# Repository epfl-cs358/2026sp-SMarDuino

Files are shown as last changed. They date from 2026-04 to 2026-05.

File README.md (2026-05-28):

# SMarDuino : Pick and Place Machine
Assembling electronic boards manually is a slow and error-prone task. Professional **Pick and Place** machines are often expensive or limited in the thickness of components they can handle.

**SMarDuino** transforms a standard **Prusa i3 MK3S+ 3D printer** into a high-precision automated assembly station. By repurposing the printer's rigid frame and precise motion system, we create a machine capable of:
*   Picking different SMD components.
*   Correcting orientation via a **Bottom Camera (OpenCV)**.
*   Placing them accurately on a PCB using a vacuum-controlled nozzle.

## Table of contents
- [The final product](#the-final-product)
- [Bill of materials](#bill-of-materials)
- [Before you start](#before-you-start)
- [Build your machine](#build-your-machine)
    - [1. Nozzle holder](#1-nozzle-holder)
        - [1.1 X-carriage](#11-x-carriage)
        - [1.2 Nozzle tips](#12-nozzle-tips)
        - [1.3 Nozzle](#13-nozzle)
    - [2. Plate](#2-plate)
        - [2.1 The base plate](#21-the-base-plate)
        - [2.2 Feeders: tape](#22-feeders-tape)
        - [2.3 Feeders: individual pieces](#23-feeders-individual-pieces)
        - [2.4 Camera holder](#24-camera-holder)
        - [2.5 PCB holder](#25-pcb-holder)
        - [2.6 Tip holder](#26-tip-holder)
    - [3. On the printer body](#3-on-the-printer-body)
        - [3.1 Pump holder](#31-pump-holder)
        - [3.2 Limit switches](#32-limit-switches)
    - [4. Electronics box](#4-electronics-box)
- [Wire your machine](#wire-your-machine)
    - [1. Electronics and Power](#electronics-and-Power)
    - [2. Camera and computer vision](#camera-and-computer-vision)
---

### The final product
[![Demo GIF]
*Watch our full demo video here: [Project Video Link]*](https://github.com/user-attachments/assets/6840ac97-82fd-42fa-adcd-1b4209363f77)
## Demo video
[See the full demo for big and little components](/github.com/epfl-cs358/2026sp-SMarDuino/issues/44#issuecomment-4560899484)

---

## Bill of materials
### ***Electronics***
*   **Arduino Mega 2560** Board (x1)
*   **Arduino Uno** (x1)
*   **CNC** Shield (x1)
*   Stepper motor **17HS4401** (x5)
*   **A4988** driver (x5)
*   **Air pump RF370** (x1)
*   Air pump tubes (interior diameter 2.5mm and 4mm) (x1)
*   **USB bottom camera** (x1)
*   **USB isolator** (x1)
*   Power supply **12V 10A** (x1)
*   DC Jack (x1)
*   One buck convertor (x1)
*   **8-LED WS2812B NeoPixel** ring light (x1)
*   Jumper wires 

### ***Mechanical parts***
*   **Prusa i3 MK3S+** 3D printer 
*   **MDF board**
*   M2.5 and M3 Screws and nuts
*   2m **Purecrea GT2 belt** (6mm) (x1)
*   Bearing (x1)
*   Bearing (x1)
*   Spring (x1)
*   Insert (x1)
*   Steel rod (x2)

### ***Have access to*** 
*   3D printer with **PETG filament** 
*   Laser cutting machine

---

## Before you start
Before assembling the new parts, you first need to remove some of the original ones from your 3D printer. Grab a screwdriver and remove:
* The heated bed
* The extruder
* If needed, the belts — replace them with new ones

## Build your machine

### 1. Nozzle holder
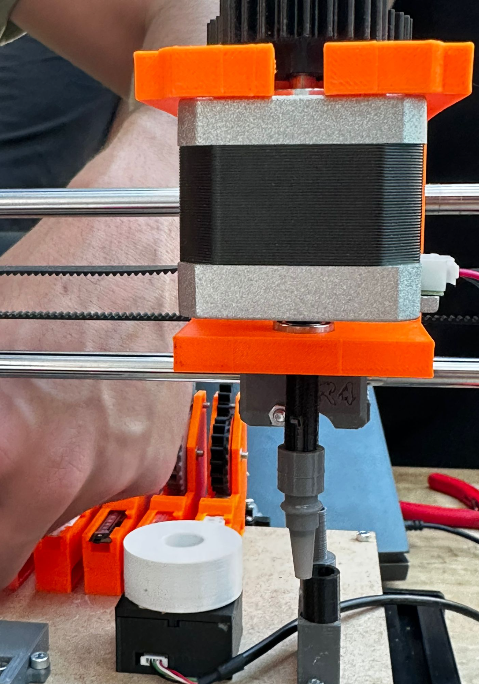
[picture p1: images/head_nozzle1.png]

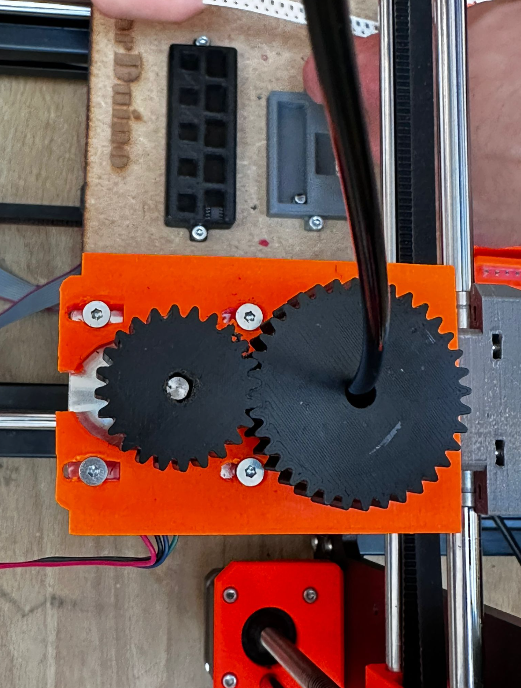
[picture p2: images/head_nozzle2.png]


#### ***1.1 X-carriage***

This assembly replaces the extruder and integrates both the nozzle holder and the feeder-advance trigger. To build it, print the following parts:
* X-carriage
* Nozzle head

Once printed, route the short timing belt through the two X-carriage halves and fasten them together along with the nozzle head. You then need to install:
* The two bearings in their designated seats
* The stepper motor used for nozzle rotation

#### ***1.2 Nozzle tips***
There are currently two tip sizes:
* A small one for components such as resistors, LEDs, etc.
* A larger one for components such as ICs, timers, etc.

PETG is not suitable here — it lacks the dimensional accuracy needed for a 1 mm bore. We therefore printed the tips in resin.

#### ***1.3 Nozzle***
The nozzle is a tube that passes through the two bearings in the nozzle head. Its rotation is driven by the stepper motor through a gear pair. Print the following:
* The nozzle
* The gear

Mount the gear on the stepper-motor shaft, then slide the nozzle through the bearings so the two gears mesh.

### 2. Plate
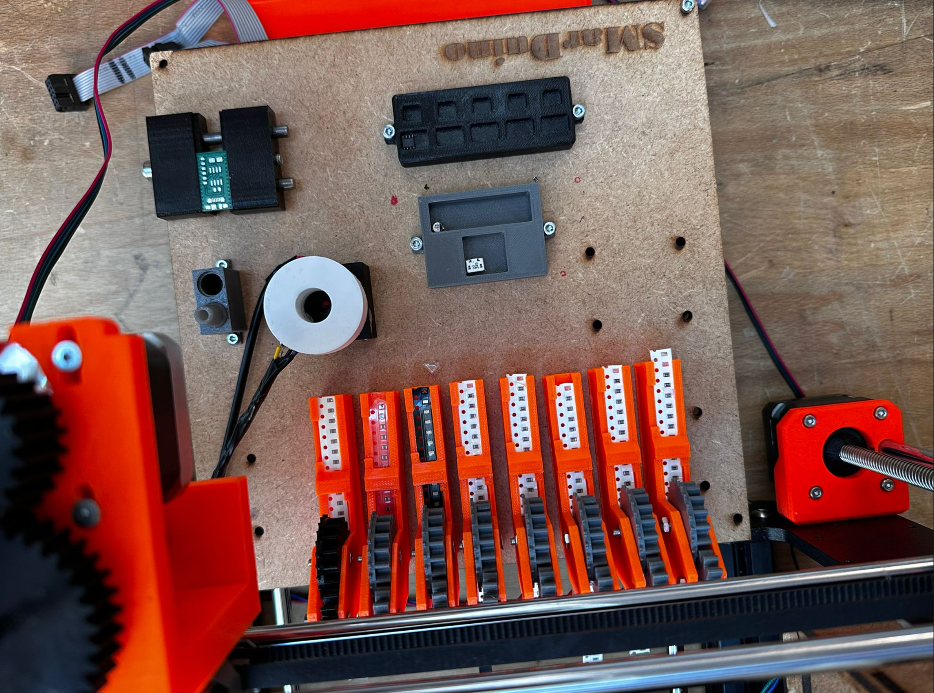
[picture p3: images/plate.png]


#### ***2.1 The base plate***
This replaces the heated bed. It is laser-cut from 4 mm MDF. To stabilize it, first print the spacers that go underneath, then screw the whole assembly down.

#### ***2.2 Feeders: tape***
After evaluating several designs, we settled on a passive mechanical feeder actuated by the nozzle itself. This is a stable and reliable system that also reduces the electrical load and the number of cables routed across the plate.

To build one, print these three pieces:
* Bottom sprocket
* Top gear
* Feeder body

Fasten the bottom sprocket and top gear to the feeder body with screws and nuts, then screw the feeder onto the base plate.

**How it works.** The head moves to the feeder and the vacuum nozzle descends into one of the holes on the tape's carrier strip. A linear move along the tape's axis then pulls the strip forward by one pitch, advancing the next component into the pickup position.

#### ***2.3 Feeders: individual pieces***
For our demo, we hard-designed dedicated holders that fit specific components by geometry. We recommend you either do the same for the components in your own build or rely on additional tape feeders instead.

#### ***2.4 Camera holder***
A small 3D-printed enclosure that holds the bottom-vision camera together with a diffuser for the LED ring light. Print:
* Light diffuser
* Camera holder

Glue the diffuser to the camera box.

#### ***2.5 PCB holder***
Start by printing the two parts contained in the file `PCBHolder`.

The holder uses a spring-loaded clamping design. The assembly consists of two rods, a screw, a spring, and a threaded insert pressed into the moving jaw, which together allow controlled translation to clamp PCBs of different widths. (Refer to the image for details.)

#### ***2.6 Tip holder***

For now this part is only used to store the tips, but it is intended to become the docking station for an automatic tip-change routine.

### 3. On the printer body
#### ***3.1 Pump holder***
A simple bracket mounted on top of the printer frame. Print it and slide the vacuum pump into it.

#### ***3.2 Limit switches***
Limit switches serve three purposes:
* **Homing** — establishing the machine's zero reference at startup
* **Crash protection** — stopping a motor before the head reaches a mechanical end-stop
* **Workspace bounds** — defining the usable travel of each axis in software

We installed one switch per axis (X, Y, Z), three in total. Print the three switch brackets and make sure they are rigidly fixed — a large share of calibration accuracy issues trace back to a loose limit-switch mount.

### 4. Electronics box
To keep the wiring tidy and protected, we designed a laser-cut MDF enclosure. The bottom is left open for easy power-supply routing and Arduino access, and a sliding door provides quick access for last-minute adjustments. 

Once all the parts are cut, assemble them with wood glue. When the box has set, fasten it to the same side of the printer as the X-axis motor, then mount the control circuit on the right-hand inner wall and close the door.

---
## Wire your machine
### 1. Electronics and Power
To avoid electrical noise, we implemented a **Dual Power Supply** system:
1.  **PSU A (12V/10A)**: Dedicated to the 5 high-current stepper motors.
2.  **BUCK Convertor** : from 12V to 5V for the pump

The final electronic architecture of the project contains:

- Arduino Mega connected to the CNC Shield
- Five stepper motor drivers installed and configured
- X, Y, Z and rotation motors connected
- Limit switches added for homing
- Vacuum pump controlled using a transistor switching circuit
- The transistor allows the Arduino to safely activate and deactivate the pump
- Buck converter used to provide a stable power supply for the pump
- Camera system connected for component alignment
- Common ground shared between all electronic modules

This setup allows the machine to perform the full pick-and-place workflow:
homing, component pickup, camera alignment, and PCB placement.
**Circuit Schematic:**
![Electronics Diagram]()
(Capture d'écran 2026-05-21 030021

### 2. Camera and computer vision
The bottom-vision camera looks **upward** at the nozzle so that, with a component held against the tip, the system can verify its orientation before placement and apply a rotation correction if needed.

The camera is paired with an **8-LED WS2812B NeoPixel ring** (32 mm outer / 18 mm inner diameter) that surrounds the lens. Ring illumination is essential here: it provides even, shadow-free lighting on the underside of the component, which is what the vision pipeline relies on to extract a clean silhouette and a stable orientation reading. The ring is driven from a single Arduino digital pin via the Adafruit NeoPixel library.

#### ***Wiring Diagram***
Based on the implementation, the connections are as follows:

| Ring Light Wire | Arduino Pin | Function |
| :--- | :--- | :--- |
| **Red** | **5V** | Power Supply (Stable 5V for LED consistency) |
| **Black** | **GND** | Ground |
| **Purple/blue** | **D10** | Signal / Control Pin 10 |
| **Yellow** | **D11** | Signal / Control Pin 11 |

---

## Running the software

### Software Layers
SMarDuino runs on a three-tier software architecture:

*   **Layer 1 (Firmware)**: Custom G-Code interpreter on Arduino Mega to handle XYZ movements and vacuum solenoid. [README of the WebApp](./3d-placer-monitor/README.md).
*   **Layer 2 (Vision)**: Python script using **OpenCV** to detect component contours, extract rotation angles, and send correction commands. [README of the computer vision](./computer_vision/README.md).
*   **Layer 3 (UI)**: A web dashboard to upload PCB design files (CSV) and monitor the placement progress in real-time.
*   
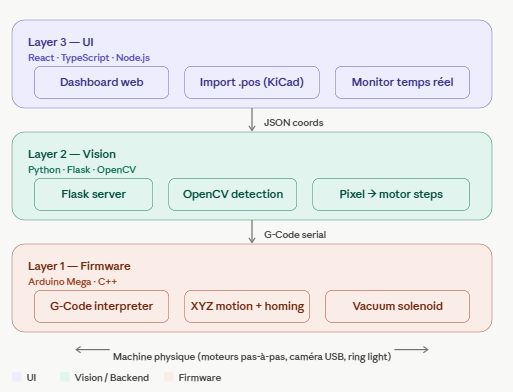
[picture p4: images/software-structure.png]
Architecture
  

### Prerequisites
- **Node.js** ≥ 18 and **npm**
- **Python** ≥ 3.10 with `pip`
- **Arduino IDE** (or `arduino-cli`)
- A USB-A cable to the Arduino Mega

### 1. Flash the firmware
1. Open `3d-placer-monitor/placer_4axis/placer_4axis.ino` in the Arduino IDE.
2. Install the **AccelStepper** library via *Sketch → Include Library → Manage Libraries → search "AccelStepper" → Install*.
3. Select board: **Arduino Mega 2560**, select the right serial port, click **Upload**.
4. Open the Serial Monitor at **9600 baud** to confirm the `READY` banner appears, then close it (only one process can own the serial port at a time).

### 2. Start the web dashboard
```bash
cd 3d-placer-monitor
npm install
npm start
```
Open **http://localhost:3000** for the Monitor view, or **http://localhost:3000/placement.html** for the Placement view. Pick the Arduino's COM port from the dropdown and click **Connect**.

### 3. Run the bottom-vision module
```bash
cd computer_vision
python vision_bridge.py --camera 1 --port 5001 --pcb "C:path\to\your\pos\file.csv"
```
Open it on **http://localhost:3000/vision.html** 

Change the camera index if it is the wrong one

## Acknowledgments

### Contributers
*   [**Alae Messaoudi**](https://github.com/alaemessaoudi)
*   [**Khalil Romdhane**](https://github.com/khalilromdhane)
*   [**Yahya Boussaadia**](https://github.com/yahyaboussaadia)
*   [**Yosr Hallab**](https://github.com/yosrhallab)
*   [**Zeineb Sellami**](https://github.com/zeinebsellami) 

We would like to thank our professor and TAs for the guidance and the patience throughout the whole semester. Special thanks to the friends who showed up, stayed late, and cheered when a single resistance finally landed where it was supposed to.
And a moment of silence, for all the A4988 drivers who gave their lives so this project could move. Gone, but not forgotten. 

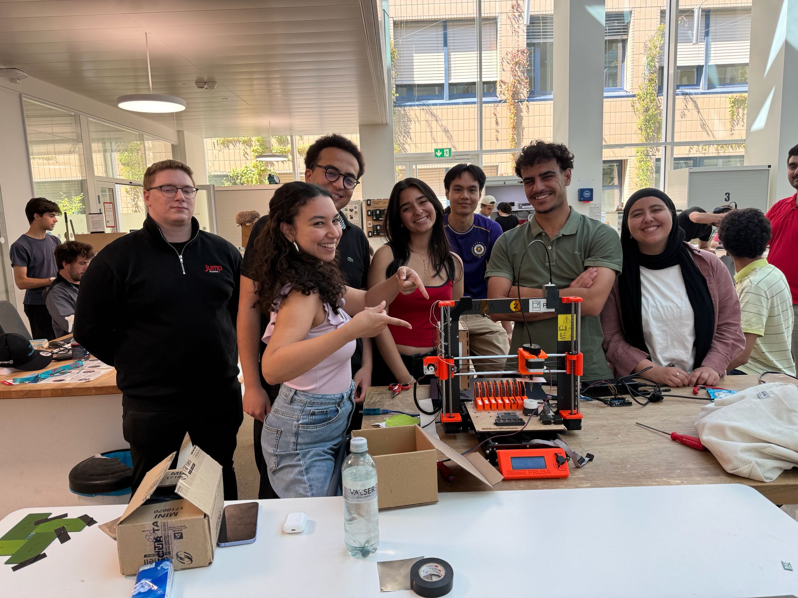
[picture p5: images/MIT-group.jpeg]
team photo


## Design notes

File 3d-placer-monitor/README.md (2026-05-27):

# 3D Placer — Web Control System

Web-based monitor & control for a 4-axis (X, Y, Z, R) pick-and-place machine using a CNC Shield + Arduino Mega.

## ✨ Features

- 📡 **Live monitoring** — X / Y / Z / R positions in real time
- 🗺️ **XY trail map** — visual movement history
- 📷 **USB webcam feed**
- 📂 **KiCad .pos import** — drag & drop component placement files
- ⚙️ **Capture buttons** — jog the head, click ⊕ to grab the current position
- ⚙️ **Persistent config** — feeders, camera, PCB origin saved to disk
- 🎯 **Automated placement** — full pick & place workflow
- ⏯️ **Run controls** — Start / Pause / Skip / Stop
- 🔒 **Limit switch homing** — real homing with NC switches
- ⌨️ **Manual commands** — send any command directly to the Arduino

---

## 🔌 Hardware

**Board:** Arduino Mega 2560 + CNC Shield V3

| Function | Pin | Notes |
|---|---|---|
| X STEP / DIR | 2 / 5 | CNC Shield X slot |
| Y STEP / DIR | 3 / 6 | CNC Shield Y slot |
| Z STEP / DIR | 4 / 7 | CNC Shield Z slot |
| R STEP / DIR | 18 / 17 | Separate driver (rotation) |
| R ENABLE | 19 | Dedicated enable for rotation driver |
| ENABLE (X/Y/Z) | 8 | Shared CNC Shield enable |
| Vacuum pump | A0 | Via relay or MOSFET |
| X limit switch | 14 | NC, wired to GND, INPUT_PULLUP |
| Y limit switch | 15 | NC |
| Z limit switch | 16 | NC |

**Homing directions:** X positive, Y negative, Z negative

---

## 🛠️ Setup

### 1. Install Node.js
https://nodejs.org (v18+)

### 2. Install dependencies
```bash
cd 3d-placer-monitor
npm install
```

### 3. Install AccelStepper library
Arduino IDE → Sketch → Include Library → Manage Libraries → search **"AccelStepper"** → Install

### 4. Upload the Arduino sketch
Open `placer_4axis.ino` → select **Arduino Mega 2560** → Upload.

### 5. Start the web server
```bash
npm start
```

### 6. Open the dashboards
- Monitor:   http://localhost:3000
- Placement: http://localhost:3000/placement.html

---

## 📡 Arduino command protocol

Every command returns `OK` or `ERR: <reason>` when complete.

| Command | Description |
|---|---|
| `MOVE X<n> Y<n> Z<n> R<n>` | Absolute move (any subset of axes) |
| `PICK` | Lower Z to Z_PICK, vacuum ON, raise Z |
| `PLACE` | Lower Z to Z_PLACE, vacuum OFF, raise Z |
| `VAC ON` / `VAC OFF` | Manual vacuum control |
| `HOME` | Home all axes (Z first for safety) |
| `HOME X` / `HOME Y` / `HOME Z` | Home one axis |
| `STATUS` | Report current X Y Z R |
| `STOP` | Immediate stop |
| `SPEED <n>` | Set max speed in steps/sec |

**All coordinates are in STEPS, not mm.** What you send is what the motor does.

---

## 🎯 Placement workflow

1. **Home the machine** — send `HOME` (uses limit switches)
2. **Jog the head** to each fixed position using the JOG panel
3. **Click ⊕ CAPTURE** to grab the current position into the config:
   - PCB origin (bottom-left corner of where the PCB will sit)
   - Camera position
   - Z Travel (safe height to fly between points)
   - Z Pick (touching the feeder)
   - Z Place (touching the PCB)
   - Each feeder XY (one ⊕ per feeder row)
4. **Set Steps per mm** — calibrate so .pos mm coords convert correctly
5. **Click SAVE CONFIG**
6. **Export .pos from KiCad** → File → Fabrication Outputs → Component Placement
7. **Drag the .pos file** onto the upload zone in the placement dashboard
8. **Click ▶ START** — the machine runs through every component

---

## 📏 Calibrating "steps per mm"

The .pos file uses mm. Your machine uses steps. The conversion factor:

1. From the dashboard, send `HOME` then `MOVE X1000`
2. The head moves 1000 steps. **Measure the distance in mm.**
3. Compute: `steps_per_mm = 1000 / mm_moved`
4. Enter this value in the SETUP panel → SAVE CONFIG

Typical values:
- GT2 belt + 20T pulley + 1/16 microstep: ~80
- Leadscrew M5 + 1/16 microstep: ~400

---

## 🔒 Limit switch homing

The sketch implements real homing using your NC limit switches:
- **Each axis drives at a constant speed** toward its switch
- **The motor stops the instant the switch triggers** (NC switch opens when pressed → pin reads HIGH)
- **Current position is set to 0** at the switch
- **During normal moves**, the same switches act as safety: if the motor is moving *toward* its switch and the switch triggers, the motor stops immediately (with debouncing to avoid false triggers)

---

## ⚠️ Safety notes

- **Close Arduino IDE Serial Monitor** before running `npm start` (only one program can use a COM port)
- **Set driver current limits** before powering motors (~0.5-1A to start)
- **Add 100µF capacitor** across VMOT/GND near each driver
- **Test moves at low speed first**
- **Always `HOME`** at startup so position is known

---

## 🐛 Troubleshooting

| Problem | Fix |
|---|---|
| "Cannot open COM port" | Close Arduino IDE Serial Monitor |
| Z homes but doesn't stop at switch | Wrong `Z_LIMIT_IS_POSITIVE` value in the sketch |
| Motor moves wrong direction in homing | Flip sign of `_HOMING_SPEED` constant |
| All axes drift over time | Driver current too low — increase trim pot voltage |
| Component placed wrong spot | Re-capture PCB origin / verify rotation |

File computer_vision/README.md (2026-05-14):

# Vision PnP — Bottom-View Orientation System

SMD pick-and-place orientation checker for a Prusa MK3S+ conversion.
One upward-facing camera is mounted on the bed; components are inspected
after pickup, before placement.

---

## Files

| File | Purpose |
|---|---|
| `orientation_engine.py` | Detection core — `load_pcb`, `VisionPipeline`, `check_orientation` |
| `footprint_envelopes.py` | Geometric envelopes for WRONG_PART detection |
| `placement_sequencer.py` | Production orchestrator — `PlacementSequencer` |
| `run_placement.py` | Automated placement CLI (production use) |
| `pnp_bottom_vision.py` | Manual debug / tuning tool (keep for calibration) |
| `camera_diagnostic.py` | Threshold-tuning utility |
| `test_pnp_vision.py` | Full test suite (no camera or Arduino required) |
| `pcb_centroid.csv` | Example centroid file |

---

## Quick start

```bash
pip install opencv-python pyserial numpy

# Manual debug tool (keyboard navigation)
python pnp_bottom_vision.py

# Automated placement loop
python run_placement.py

# Run all tests (no hardware required)
python test_pnp_vision.py
```

---

## Sequencer flow

```
load_job(pcb_file)
      │
      ▼
┌─────────────────────────────────────────────────────┐
│  for each component in centroid order:              │
│                                                     │
│  1. Wait for trigger (READY <des> or function call) │
│  2. Capture one frame from bottom camera            │
│  3. VisionPipeline.run(frame) → DetectedComponent   │
│  4. is_consistent_with(detected, footprint)         │
│        ↓ fail → WRONG_PART  halt, operator skip     │
│  5. check_orientation(detected, pcb_comp)           │
│        PLACE     → send JSON, wait ACK, advance     │
│        ROTATE_*  → send JSON, wait ACK, retry once  │
│        REJECT    → WRONG_PART halt                  │
└─────────────────────────────────────────────────────┘
```

### Keyboard shortcuts (run_placement.py)

| Key | Action |
|---|---|
| `SPACE` | Process current expected designator |
| `s` | Skip (operator override after WRONG_PART halt) |
| `r` | Reset queue to start |
| `d` | Toggle debug body-mask overlay |
| `q` | Quit |

---

## Serial protocol

### Host → Arduino (one JSON line per component)

```json
{"des":"R1","ok":true,"type":"SMD_PASSIVE","delta":-12.3,"action":"ROTATE_CCW","conf":0.72,"method":"pads","pads":2,"pin1":"unknown"}
```

| Field | Type | Description |
|---|---|---|
| `des` | string | Designator from centroid file |
| `ok` | bool | `true` when within ANGLE_TOLERANCE (5°) |
| `type` | string | Detected component class |
| `delta` | float | Signed rotation needed (CCW-positive, degrees) |
| `action` | string | `PLACE` / `ROTATE_CW` / `ROTATE_CCW` / `REJECT` / `WRONG_PART` |
| `conf` | float | Detection confidence 0–1 |
| `method` | string | Angle method used: `pads` / `pca_pads` / `pca` / `bbox` |
| `pads` | int | Pad count detected |
| `pin1` | string | `"left"` / `"right"` / `"unknown"` — IC pin-1 hint |

### Arduino → Host (ACK)

```
ACK R1 PLACED
ACK U2 ROTATED
ACK R3 ERROR
```

The sequencer blocks up to **5 seconds** for the ACK.  Timeout or `ERROR`
halts the sequence and requires operator intervention.

---

## Rotation convention

KiCad uses **CCW-positive degrees**.  The engine preserves this end-to-end.
The Arduino receives the same sign convention — positive delta means rotate
counter-clockwise.

For components placed on the **bottom layer**, the required rotation is
mirrored: `required_angle = (-pcb_rotation) % 360`.

---

## Footprint envelopes (WRONG_PART detection)

`footprint_envelopes.py` maps footprint strings to geometric envelopes
`(pad_count_range, aspect_ratio_min, body_area_range)`.  Matching is by
case-insensitive substring, so `"R_0805"` matches both `"R_0805"` and
`"Resistor_SMD:R_0805_2012Metric"`.

If no envelope is defined for a footprint the check is skipped (proceed).
To add a new footprint, add an entry to `FOOTPRINT_ENVELOPES` in
`footprint_envelopes.py`.

---

## Pin-1 detection (IC packages)

Bottom-view pin-1 detection for symmetric SOIC packages is **inherently
unreliable** — many ICs look identical from below.  The sequencer surfaces a
`pin1_side` hint (`"left"` / `"right"` / `"unknown"`) based on pad-area
asymmetry, but proceeds regardless of the result.  The feeder orientation is
the real source of truth.  A top camera would make this reliable; we can
revisit when/if one is added.

---

## Running tests

```bash
python test_pnp_vision.py
```

Runs three suites:

1. **Vision tests** — synthetic frames through the full detection pipeline
2. **Loader tests** — CSV and KiCad PCB file parsers
3. **Sequencer tests** — `PlacementSequencer` in offline mode (no hardware)

All tests run without a camera or Arduino.

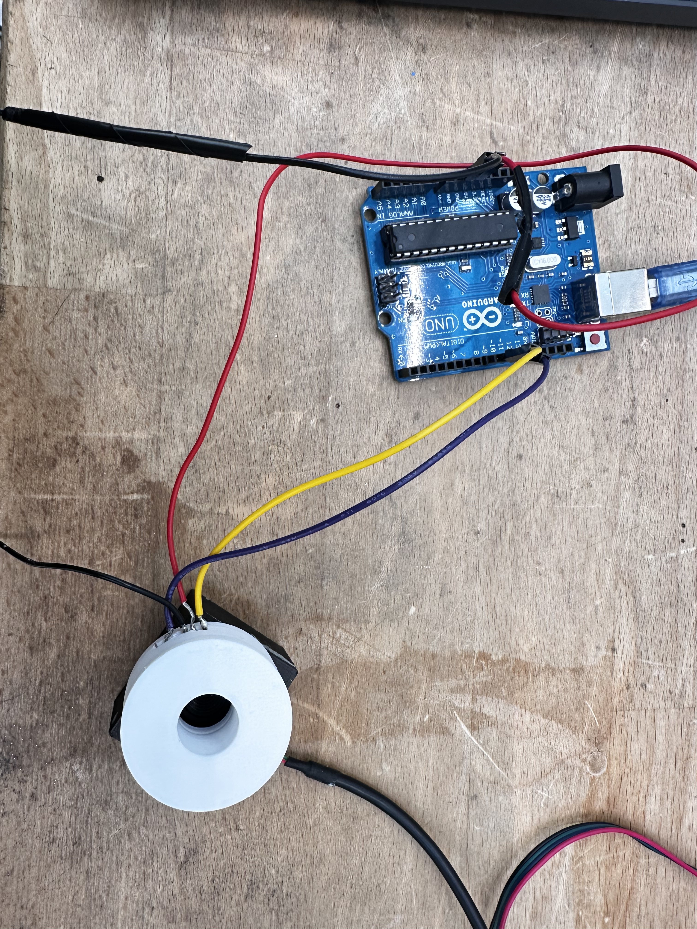
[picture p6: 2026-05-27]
images/computer_vision_electronics3.jpeg

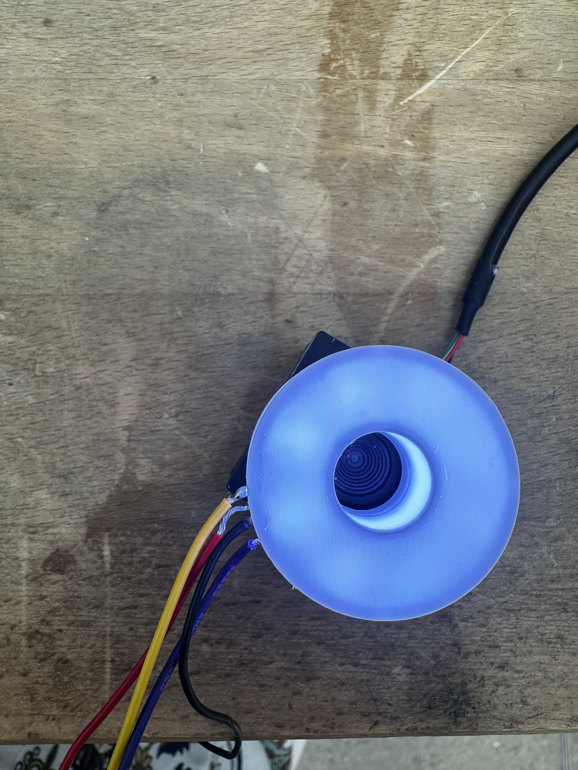
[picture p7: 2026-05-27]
images/computer_vision_electronics1.jpeg

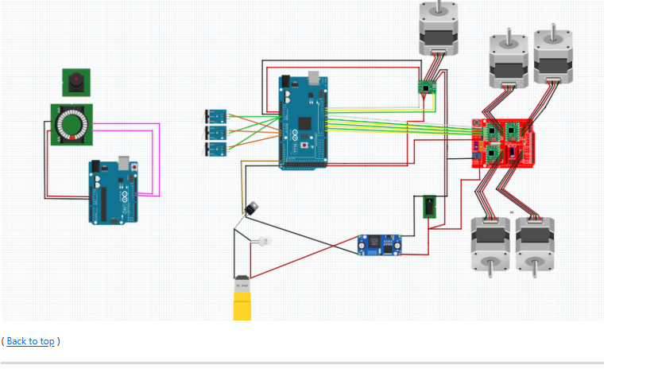
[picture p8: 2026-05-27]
images/electronic circuit.png

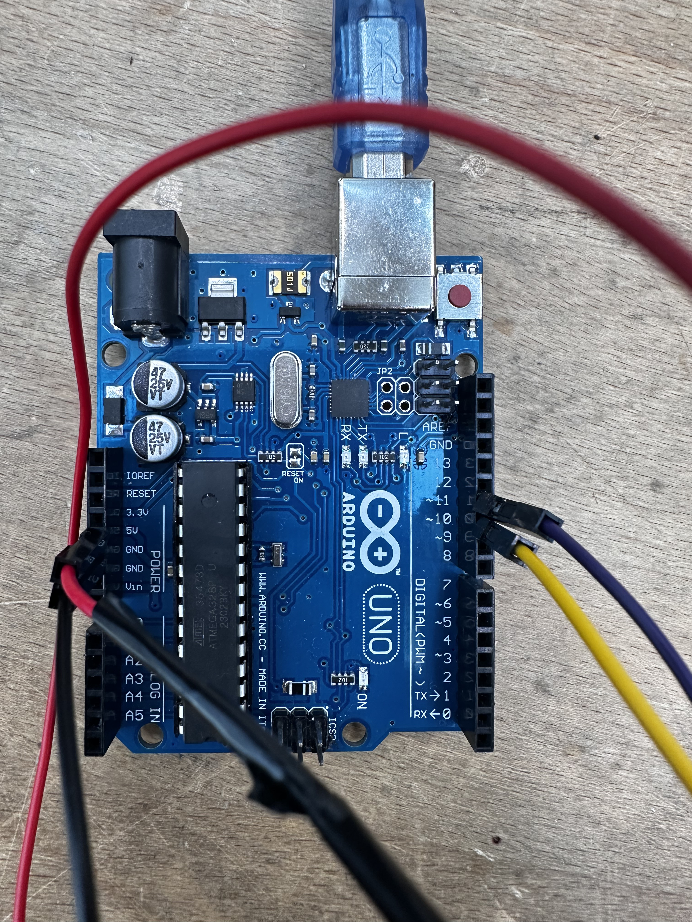
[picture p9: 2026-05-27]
images/computer_vision_electronics2.jpeg

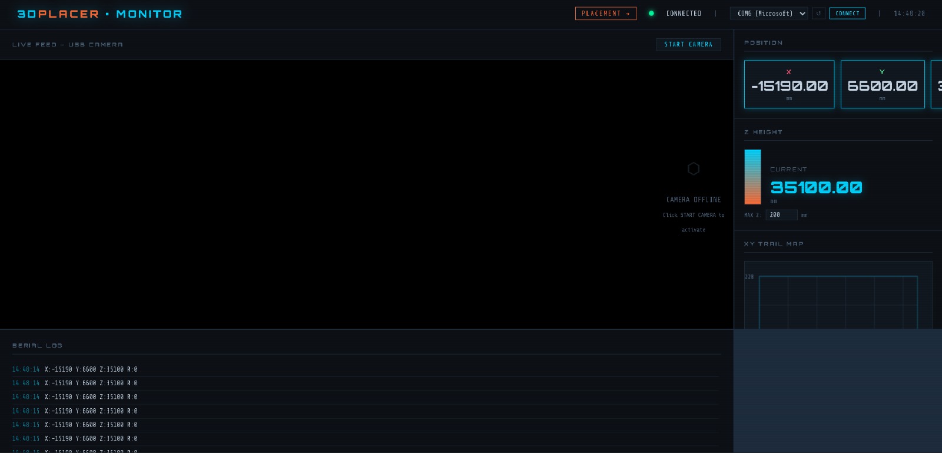
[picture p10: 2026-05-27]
images/Webapp_monitor.jpeg

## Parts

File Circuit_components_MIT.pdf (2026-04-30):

## Bill of Materials

SMD PCB Circuits — Pick & Place Demonstration

All components available in Switzerland

April 29, 2026

Contents

1 Circuit 1 — Flashing LED (NE555 Astable) | 2
2 Circuit 2 — LED Chaser / Knight Rider (NE555 + CD4017) | 2
3 Combined Bill of Materials | 2

Circuit 1 — Flashing LED (NE555 Astable)

Description

A minimal SMD LED flasher based on the NE555 timer IC in astable mode. Flashes a single red LED at a fixed frequency set by resistors and capacitor. Power via USB Micro-B connector. Repository: github.com/ItsKarlito/flashing-led

Component List

- 1x NE555DR — Timer IC, SOIC-8
- 1x LED, Red, SMD 0805
- 1x USB Micro-B Connector, Female, SMD
- 1x Capacitor 1 uF, SMD Electrolytic
- 1x Resistor 100 kOhm, SMD 0805
- 1x Resistor 470 kOhm, SMD 0805
- 1x Resistor 270 kOhm, SMD 0805

Circuit 2 — LED Chaser / Knight Rider (NE555 + CD4017)

Description

A 10-LED running light chaser. The NE555 generates a clock in astable mode, driving the CD4017 decade counter. Each output lights one LED in sequence. Power supply: 9V DC. Reference: PCBWay — NE555 LED Chaser Board (https://www.pcbway.com/project/shareproject/NE555_IC_Timer_LED_Chaser_Board_d9795bc6.html)

Component List

- 1x NE555DR — Timer IC, SOIC-8
- 1x CD4017BM96 — Decade Counter IC, SOIC-16
- 10x LED, Red, SMD 0805
- 1x Resistor 10 kOhm, SMD 0805
- 10x Resistor 220 Ohm, SMD 0805
- 1x Capacitor 10 nF, SMD Ceramic 0805
- 1x Capacitor 10 uF, SMD Ceramic 0805

Combined Bill of Materials

Component / MPN | Qty Package | Supplier | Verified Link

NE555DR
Timer IC | 2 | SOIC-8 | mouser.ch | Search: NE555DR (https://www.mouser.ch/Search/Refine?Keyword=NE555DR)
CD4017BM96
Decade Counter | 1 | SOIC-16 | mouser.ch | Search:
| | | | CD4017BM96 (https://www.mouser.ch/Search/Refine?Keyword=CD4017BM96)
VLMS1300-GS08
LED, Red | 11 | SMD 0805 | mouser.ch | Search: VLMS1300 (https://www.mouser.ch/Search/Refine?Keyword=VLMS1300-GS08)
RND 1550805S8F2200T5E
Resistor 220 Ohm | 10 | SMD 0805,
| | 1% | distrelec.ch | Art. 30056759 (https://www.distrelec.ch/en/thick-film-smd-resistor-0805-220ohm-125mw-rnd-rnd-1550805s8f2200t5e/p/30056759)

RND 1550805S8F1002T5E
Resistor 10 kOhm | 1 | SMD 0805,
| | 1% | distrelec.ch | Art. 30056718 (https://www.distrelec.ch/en/thick-film-smd-resistor-0805-10kohm-125mw-rnd-rnd-1550805s8f1002t5e/p/30056718)

RC0805FR-07100KL
Resistor 100 kOhm | 1 | SMD 0805,
| | 1% | mouser.ch | Search:
| | | | RC0805FR-07100KL (https://www.mouser.ch/Search/Refine?Keyword=RC0805FR-07100KL)
RC0805FR-07270KL
Resistor 270 kOhm | 1 | SMD 0805,
| | 1% | mouser.ch | Search:
| | | | RC0805FR-07270KL (https://www.mouser.ch/Search/Refine?Keyword=RC0805FR-07270KL)
RC0805FR-07470KL
Resistor 470 kOhm | 1 | SMD 0805,
| | 1% | mouser.ch | Search:
| | | | RC0805FR-07470KL (https://www.mouser.ch/Search/Refine?Keyword=RC0805FR-07470KL)
C0805C103K5RACTU
Cap 10 nF | 1 | SMD 0805,
| | X7R, 50V | distrelec.ch | Art. 16572413 (https://www.distrelec.ch/en/ceramic-capacitor-10nf-50vdc-0805-10-kemet-c0805c103k5ractu/p/16572413)

EEE-FK1H010P
Cap 1 uF | 1 | SMD
| | Electrolytic | mouser.ch | Search:
| | | | EEE-FK1H010P (https://www.mouser.ch/Search/Refine?Keyword=EEE-FK1H010P)
CC0805KKX5R8BB106
Cap 10 uF | 1 | SMD 0805,
| | 25V | distrelec.ch | Art. 30288132 (https://www.distrelec.ch/en/ceramic-capacitor-10uf-25v-0805-10-yageo-cc0805kkx5r8bb106/p/30288132)

47346-0001 (Molex)
USB Micro-B | 1 | Female,
| | SMD, 5-pin | mouser.ch | Search: 47346-0001 (https://www.mouser.ch/Search/Refine?Keyword=47346-0001)

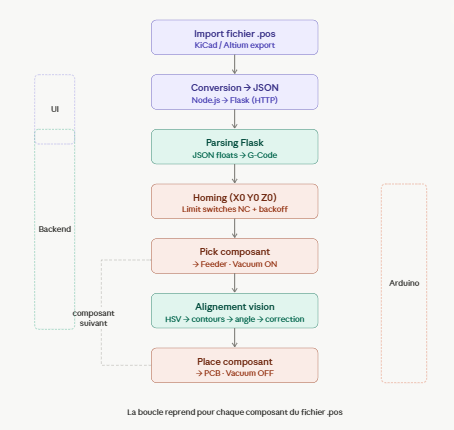
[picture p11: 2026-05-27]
images/placement-component.png

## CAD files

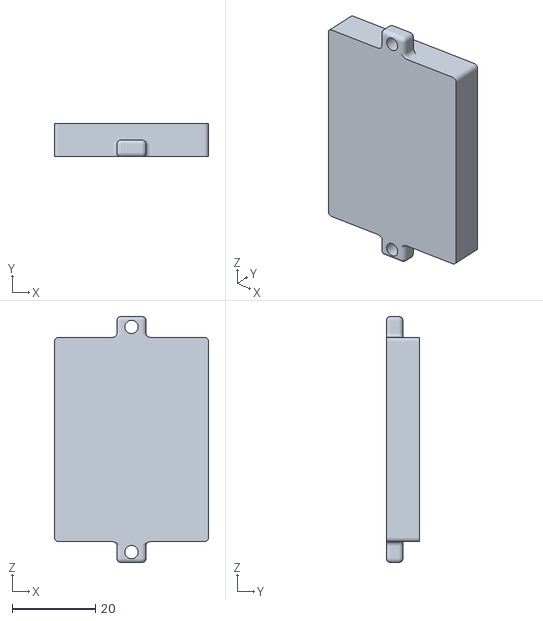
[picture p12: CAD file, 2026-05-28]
3D_designs/bigbigcomponents2.stl
37.0 x 8.00 x 59.1

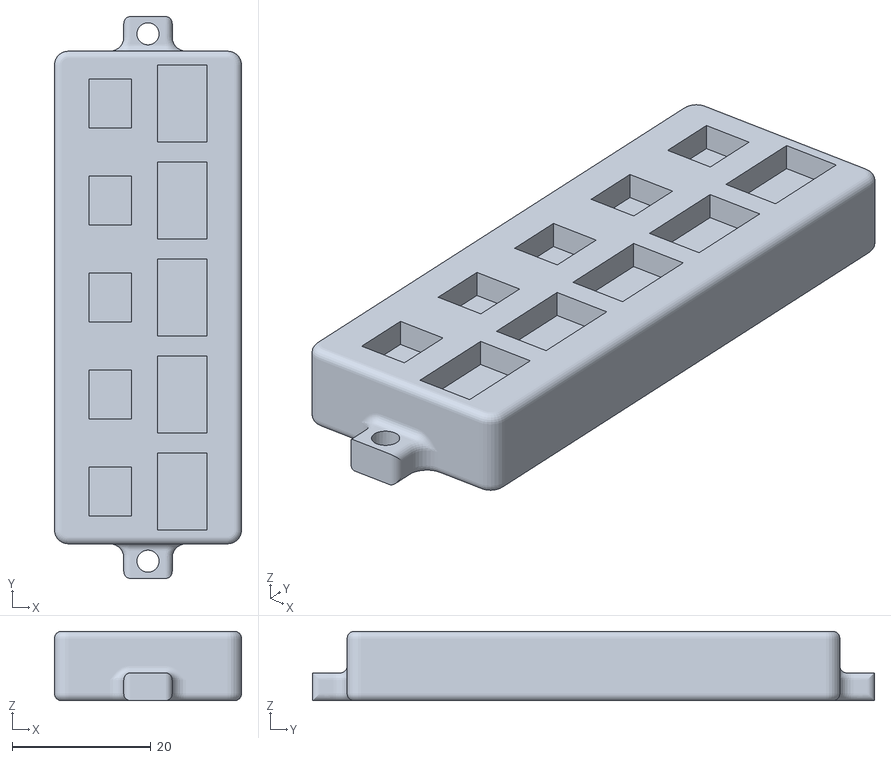
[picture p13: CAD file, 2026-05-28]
3D_designs/feeder2.stl
27.0 x 81.1 x 10.0

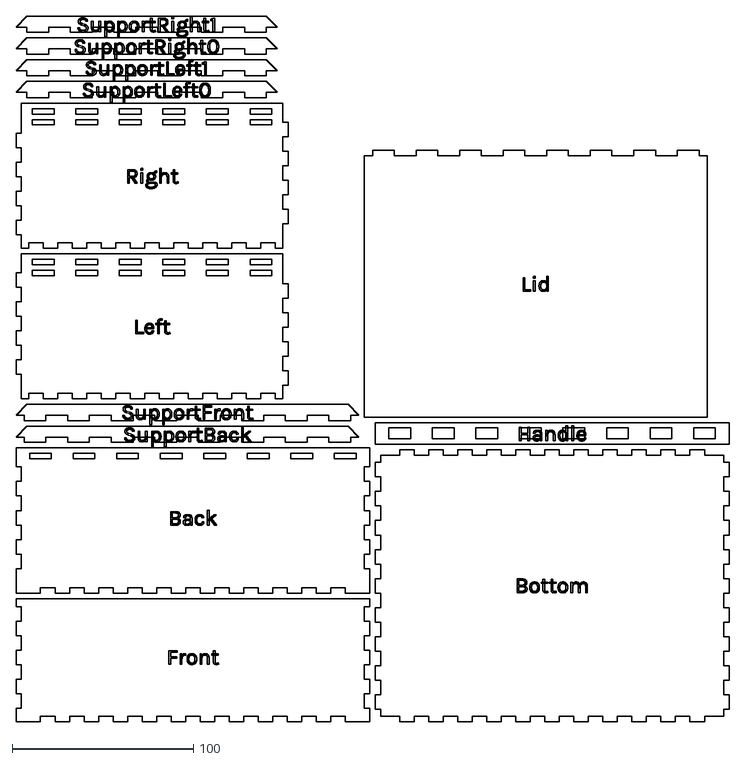
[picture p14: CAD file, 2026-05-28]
3D_designs/box (1).dxf
393.0 x 389.0

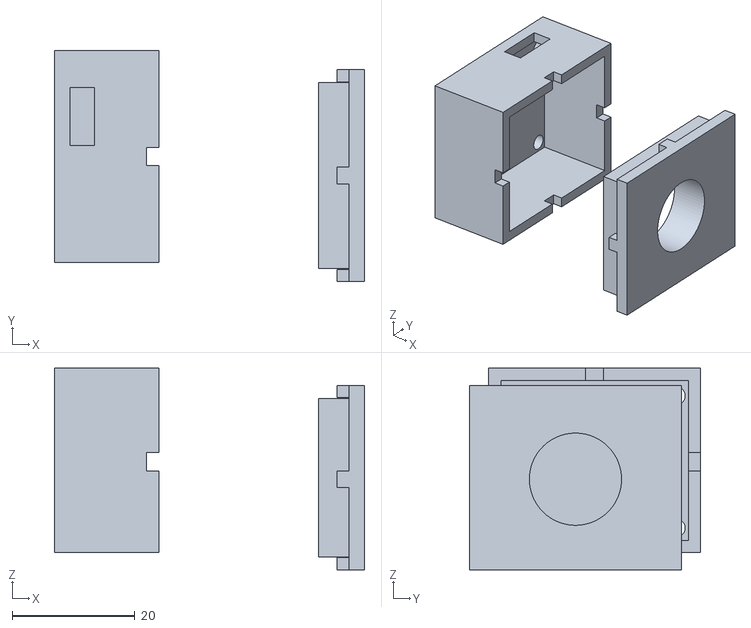
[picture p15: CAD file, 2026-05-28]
3D_designs/holdcamera.stl
50.4 x 37.6 x 32.8

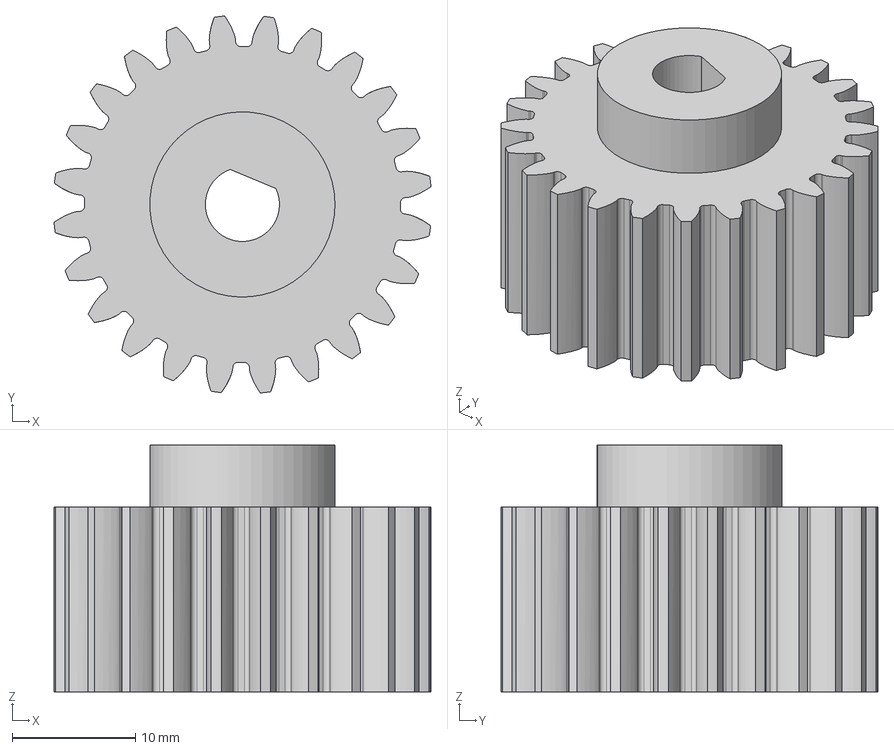
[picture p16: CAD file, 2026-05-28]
3D_designs/NozzleGear.step
30.5 x 30.5 x 20.0 mm

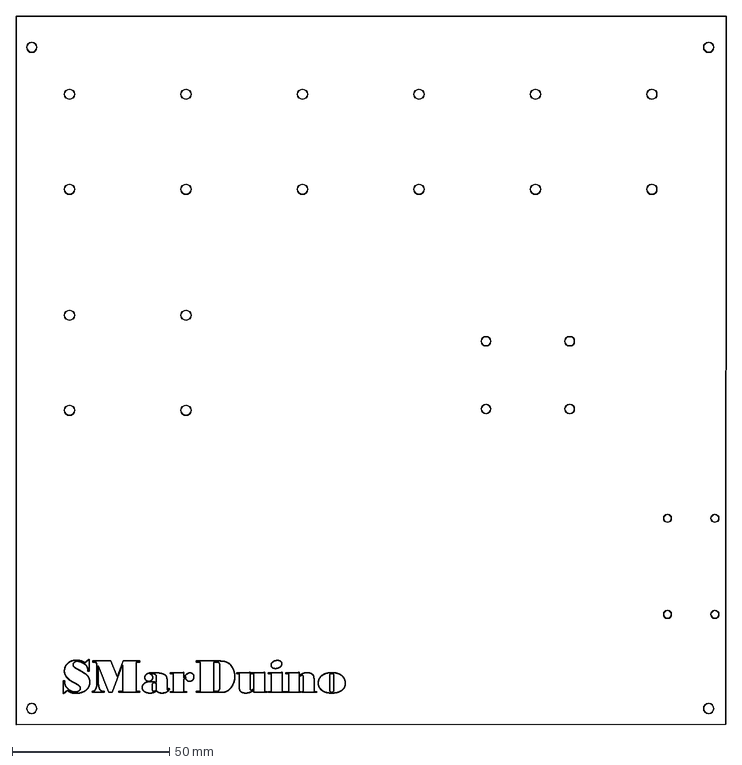
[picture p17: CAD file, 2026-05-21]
3D_designs/Plate.dxf
225.5 x 224.9 mm

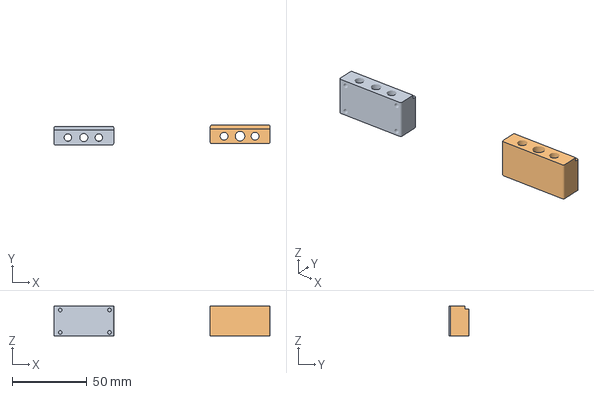
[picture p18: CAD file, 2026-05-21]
3D_designs/PCBHolder.3mf
144.6 x 13.4 x 20.0 mm
MON PCB HOLDER.stl_1
MON PCB HOLDER.stl_2

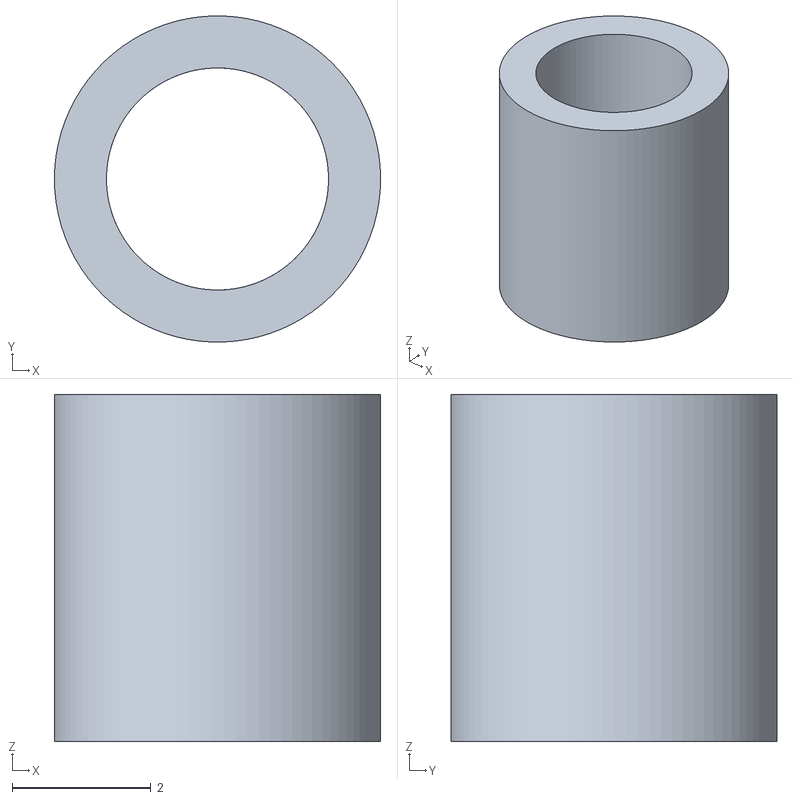
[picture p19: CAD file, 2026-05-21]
3D_designs/PlateSpacer.stl
4.70 x 4.70 x 5.00

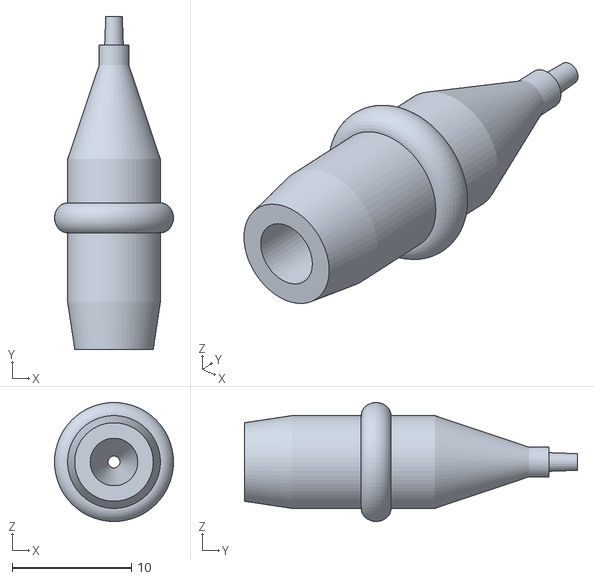
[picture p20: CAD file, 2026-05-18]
3D_designs/TipSmall.stl
10.0 x 28.0 x 10.0

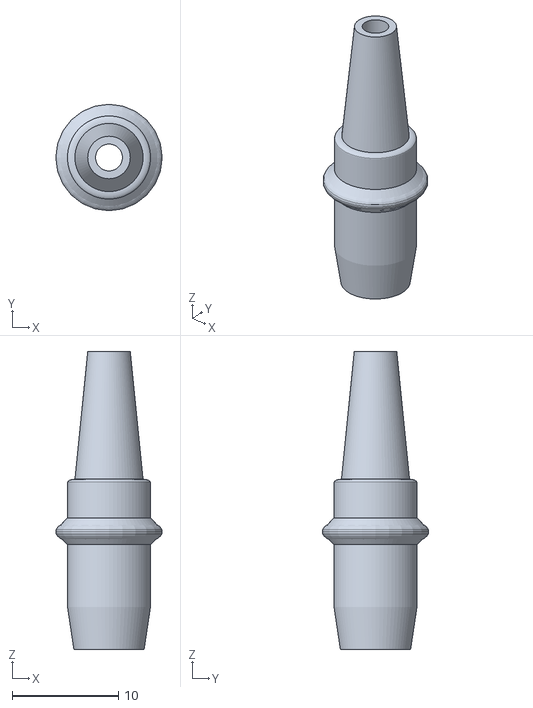
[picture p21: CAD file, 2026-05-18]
3D_designs/TipBig.stl
10.0 x 10.0 x 28.0

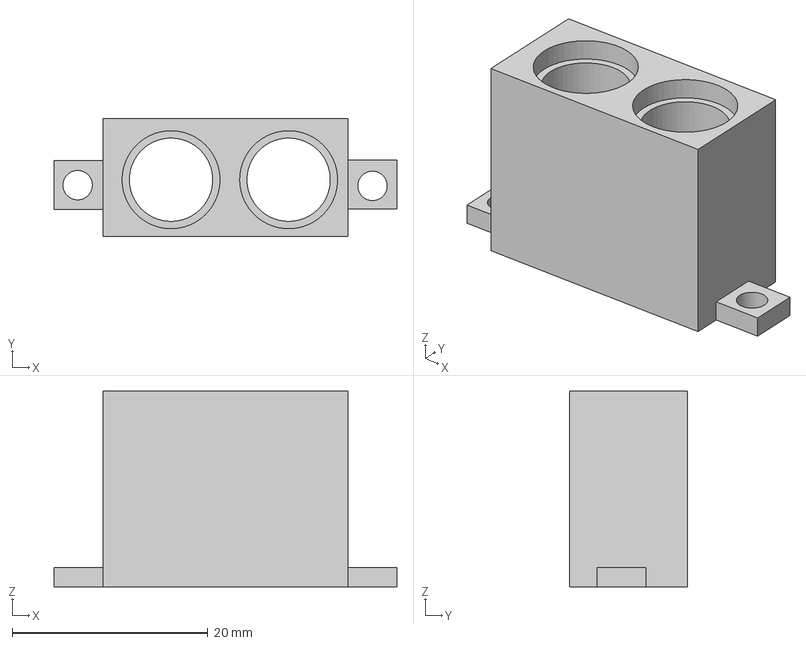
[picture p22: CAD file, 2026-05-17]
3D_designs/TipHolder.step
35.0 x 12.0 x 20.0 mm

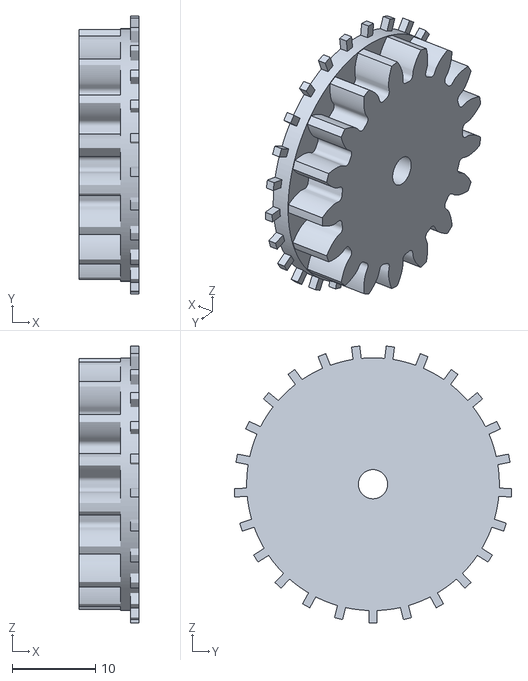
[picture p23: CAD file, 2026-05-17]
3D_designs/BottomSprocket.stl
7.20 x 33.3 x 33.2

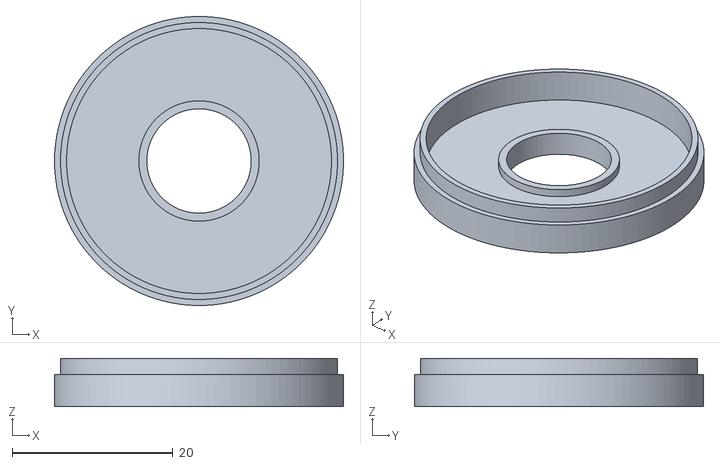
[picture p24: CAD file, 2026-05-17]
3D_designs/BottomLightHolder.stl
36.0 x 36.0 x 6.00

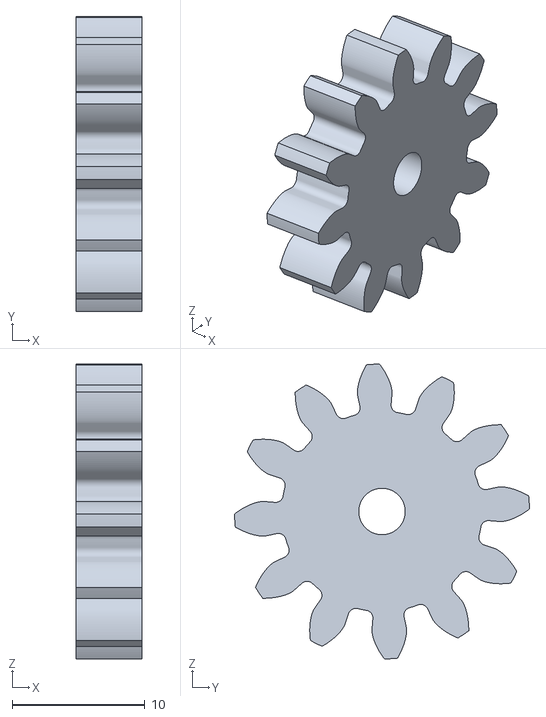
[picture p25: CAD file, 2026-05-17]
3D_designs/TopGear.stl
5.00 x 22.2 x 22.2

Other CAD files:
3D_designs/Nozzle.step
3D_designs/TopLightHolder.stl
3D_designs/NozzleHead.step
3D_designs/FeederBody.step
3D_designs/PumpHolder.stl
3D_designs/TipCap.step
3D_designs/xCarriageBack.step
3D_designs/xCarriageFront.step

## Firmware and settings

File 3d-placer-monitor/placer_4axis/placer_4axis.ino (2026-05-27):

/*
 * 3D Placer — 4-Axis Controller (webapp protocol)
 * Hardware: Arduino Mega + CNC Shield + 4× stepper drivers + vacuum pump
 *
 * Motion logic is identical to the reference sketch:
 *   - Uses motor.move(steps) for RELATIVE moves (not moveTo)
 *   - Same limit switch protection (runMotorWithLimit)
 *   - Same homing logic (homeAxis with constant-speed approach)
 *   - Same position-reporting format
 *
 * IMPORTANT — Install library first:
 *   Arduino IDE → Sketch → Include Library → Manage Libraries
 *   → Search "AccelStepper" → Install
 *
 * Protocol — every command returns "OK" or "ERR: <reason>" when complete.
 * The web app waits for that response before sending the next command.
 *
 *   MOVE X<val> Y<val> Z<val> R<val>   ABSOLUTE move (go to position X=val)
 *   STEP X<val> Y<val> Z<val> R<val>   RELATIVE move (move val steps from current)
 *   ADVANCE Y<pitch> Z<travelZ>         Tape advance from pickup position:
 *                                       Nozzle starts at pickup Z in pocket. Sequence:
 *                                         0. plunge +100 deeper to grip tape hole
 *                                         1. drag Y by -<pitch>
 *                                         2. lift Z to <travelZ>
 *                                         3. return Y by +<pitch>
 *                                         4. plunge back to deep position
 *                                       Ends with nozzle deep in pocket; caller
 *                                       should lift to travel Z after this.
 *                                       Example: ADVANCE Y430 Z5000
 *   PICK                                lower Z, vacuum ON, raise Z
 *   PLACE                               lower Z, vacuum OFF, raise Z
 *   VAC ON | VAC OFF | ON | OFF         manual vacuum control
 *   HOME                                home all axes with limit switches
 *   HOME X | HOME Y | HOME Z            home one axis
 *   ZERO                                set current position as 0 for all motors
 *   STATUS                              report current X Y Z R
 *   STOP                                immediate stop
 *   SWITCHES                            print limit switch states
 */

#include <AccelStepper.h>

// ─── PIN CONFIG (CNC Shield V3) ──────────────────────────────────────────
#define ENABLE_PIN     8
#define X_STEP_PIN     2
#define X_DIR_PIN      5
#define Y_STEP_PIN     3
#define Y_DIR_PIN      6
#define Z_STEP_PIN     4
#define Z_DIR_PIN      7
#define ROT_STEP_PIN   18
#define ROT_DIR_PIN    17
#define ROT_ENABLE_PIN 19
#define PUMP_PIN       A0
#define X_LIMIT_PIN    14
#define Y_LIMIT_PIN    15
#define Z_LIMIT_PIN    16

AccelStepper motorX(AccelStepper::DRIVER, X_STEP_PIN, X_DIR_PIN);
AccelStepper motorY(AccelStepper::DRIVER, Y_STEP_PIN, Y_DIR_PIN);
AccelStepper motorZ(AccelStepper::DRIVER, Z_STEP_PIN, Z_DIR_PIN);
AccelStepper motorR(AccelStepper::DRIVER, ROT_STEP_PIN, ROT_DIR_PIN);

// ─── HOMING CONFIG ───────────────────────────────────────────────────────
// X moves positive, Y negative, Z negative
const float X_HOMING_SPEED =  800;
const float Y_HOMING_SPEED = -800;
const float Z_HOMING_SPEED = -1500;

// Which side of the workspace is each switch on?
// true  = switch on positive end of travel
// false = switch on negative end of travel
const bool X_LIMIT_IS_POSITIVE = true;
const bool Y_LIMIT_IS_POSITIVE = false;
const bool Z_LIMIT_IS_POSITIVE = false;

// NC switches + INPUT_PULLUP:
//   not pressed → pin reads LOW
//   pressed     → pin reads HIGH
byte xLimitCounter = 0;
byte yLimitCounter = 0;
byte zLimitCounter = 0;
const byte LIMIT_DEBOUNCE_COUNT = 5;

// ─── PICK / PLACE CONFIG ─────────────────────────────────────────────────
// Relative Z moves for pick/place sequences.
// Negative = down, positive = up.
// You can tune these or override via config from the webapp.
long Z_DROP_STEPS = -500;   // how far DOWN to drop nozzle for pick/place
long Z_LIFT_STEPS =  500;   // how far UP to lift after (should equal -Z_DROP_STEPS)

// ─── STATE ───────────────────────────────────────────────────────────────
String inputBuffer = "";
unsigned long lastReport = 0;
const unsigned long REPORT_INTERVAL = 200;  // ms

// ─────────────────────────────────────────────────────────────────────────
void setup() {
  Serial.begin(9600);
  delay(2000);  // let serial stabilize after DTR reset

  // Enable CNC Shield drivers
  pinMode(ENABLE_PIN, OUTPUT);
  digitalWrite(ENABLE_PIN, LOW);

  // Enable rotation motor driver
  pinMode(ROT_ENABLE_PIN, OUTPUT);
  digitalWrite(ROT_ENABLE_PIN, LOW);

  // Pump
  pinMode(PUMP_PIN, OUTPUT);
  digitalWrite(PUMP_PIN, LOW);

  // Limit switches
  pinMode(X_LIMIT_PIN, INPUT_PULLUP);
  pinMode(Y_LIMIT_PIN, INPUT_PULLUP);
  pinMode(Z_LIMIT_PIN, INPUT_PULLUP);

  // Motor speeds & acceleration (same as reference sketch)
  motorX.setMaxSpeed(1000);
  motorX.setAcceleration(3000);

  motorY.setMaxSpeed(2000);
  motorY.setAcceleration(4000);

  motorZ.setMaxSpeed(2000);
  motorZ.setAcceleration(3000);

  motorR.setMaxSpeed(2000);
  motorR.setAcceleration(3000);

  Serial.println("READY");
  Serial.println("4-axis placer online.");
}

// ─────────────────────────────────────────────────────────────────────────
void loop() {
  readSerial();

  // X, Y, Z get limit-switch protection
  runMotorWithLimit(motorX, X_LIMIT_PIN, X_LIMIT_IS_POSITIVE, "X", xLimitCounter);
  runMotorWithLimit(motorY, Y_LIMIT_PIN, Y_LIMIT_IS_POSITIVE, "Y", yLimitCounter);
  runMotorWithLimit(motorZ, Z_LIMIT_PIN, Z_LIMIT_IS_POSITIVE, "Z", zLimitCounter);

  // R has no limit switch
  motorR.run();

  // Periodic position report
  if (millis() - lastReport > REPORT_INTERVAL) {
    reportPosition();
    lastReport = millis();
  }
}

// ─── SERIAL READ ─────────────────────────────────────────────────────────
void readSerial() {
  while (Serial.available()) {
    char c = Serial.read();
    if (c == '\n' || c == '\r') {
      if (inputBuffer.length() > 0) {
        handleCommand(inputBuffer);
        inputBuffer = "";
      }
    } else {
      inputBuffer += c;
    }
  }
}

// ─── COMMAND HANDLER ─────────────────────────────────────────────────────
void handleCommand(String cmd) {
  cmd.trim();
  String upper = cmd; upper.toUpperCase();

  if (upper.startsWith("MOVE")) {
    handleMove(cmd, false);   // absolute
  }
  else if (upper.startsWith("STEP")) {
    handleMove(cmd, true);    // relative
  }
  else if (upper.startsWith("ADVANCE")) {
    handleAdvance(cmd);
  }
  else if (upper == "PICK") {
    doPick();
    Serial.println("OK");
  }
  else if (upper == "PLACE") {
    doPlace();
    Serial.println("OK");
  }
  else if (upper == "VAC ON" || upper == "ON") {
    digitalWrite(PUMP_PIN, HIGH);
    Serial.println("OK");
  }
  else if (upper == "VAC OFF" || upper == "OFF") {
    digitalWrite(PUMP_PIN, LOW);
    Serial.println("OK");
  }
  else if (upper == "HOME") {
    doHoming();
    Serial.println("OK");
  }
  else if (upper == "HOME X") {
    homeAxis(motorX, X_LIMIT_PIN, X_HOMING_SPEED, "X");
    Serial.println("OK");
  }
  else if (upper == "HOME Y") {
    homeAxis(motorY, Y_LIMIT_PIN, Y_HOMING_SPEED, "Y");
    Serial.println("OK");
  }
  else if (upper == "HOME Z") {
    homeAxis(motorZ, Z_LIMIT_PIN, Z_HOMING_SPEED, "Z");
    Serial.println("OK");
  }
  else if (upper == "ZERO") {
    motorX.setCurrentPosition(0);
    motorY.setCurrentPosition(0);
    motorZ.setCurrentPosition(0);
    motorR.setCurrentPosition(0);
    Serial.println("OK");
  }
  else if (upper == "STATUS") {
    reportPosition();
    Serial.println("OK");
  }
  else if (upper == "STOP") {
    motorX.stop(); motorY.stop(); motorZ.stop(); motorR.stop();
    Serial.println("OK");
  }
  else if (upper == "SWITCHES") {
    printSwitches();
    Serial.println("OK");
  }
  else {
    Serial.print("ERR: unknown command: "); Serial.println(cmd);
  }
}

// ─── MOVE / STEP COMMAND ─────────────────────────────────────────────────
// MOVE X1000 Y500 Z-200 R45    → ABSOLUTE: motorX.moveTo(1000)
// STEP X1000 Y500 Z-200 R45    → RELATIVE: motorX.move(1000)
// All specified axes move simultaneously. Waits until all have arrived.
void handleMove(String cmd, bool relative) {
  long vx = 0, vy = 0, vz = 0, vr = 0;
  bool hasX = false, hasY = false, hasZ = false, hasR = false;

  int idx;
  if ((idx = cmd.indexOf('X')) >= 0) { vx = cmd.substring(idx+1).toInt(); hasX = true; }
  if ((idx = cmd.indexOf('Y')) >= 0) { vy = cmd.substring(idx+1).toInt(); hasY = true; }
  if ((idx = cmd.indexOf('Z')) >= 0) { vz = cmd.substring(idx+1).toInt(); hasZ = true; }
  if ((idx = cmd.indexOf('R')) >= 0) { vr = cmd.substring(idx+1).toInt(); hasR = true; }

  if (relative) {
    // STEP: relative moves (matches reference sketch's motor.move())
    if (hasX) motorX.move(vx);
    if (hasY) motorY.move(vy);
    if (hasZ) motorZ.move(vz);
    if (hasR) motorR.move(vr);
  } else {
    // MOVE: absolute targets
    if (hasX) motorX.moveTo(vx);
    if (hasY) motorY.moveTo(vy);
    if (hasZ) motorZ.moveTo(vz);
    if (hasR) motorR.moveTo(vr);
  }

  // Run motors until all arrive (with limit protection on X/Y/Z)
  while (motorX.distanceToGo() != 0 || motorY.distanceToGo() != 0 ||
         motorZ.distanceToGo() != 0 || motorR.distanceToGo() != 0) {
    runMotorWithLimit(motorX, X_LIMIT_PIN, X_LIMIT_IS_POSITIVE, "X", xLimitCounter);
    runMotorWithLimit(motorY, Y_LIMIT_PIN, Y_LIMIT_IS_POSITIVE, "Y", yLimitCounter);
    runMotorWithLimit(motorZ, Z_LIMIT_PIN, Z_LIMIT_IS_POSITIVE, "Z", zLimitCounter);
    motorR.run();

    if (millis() - lastReport > REPORT_INTERVAL) {
      reportPosition();
      lastReport = millis();
    }
  }

  Serial.println("OK");
}

// ─── ADVANCE COMMAND (tape feeder scroll, returns to pocket) ─────────────
// ADVANCE Y<pitch> Z<travelZ>
//   Starting condition: nozzle is DOWN in the feeder pocket (at pocket Z).
//   Sequence:
//     0. Plunge an EXTRA 100 steps deeper into the pocket (grip the tape hole)
//     1. Drag Y by -<pitch>       (scroll the tape backward while nozzle grips)
//     2. Lift Z to <travelZ>      (lift the nozzle out)
//     3. Return Y by +<pitch>     (head back to original Y over pocket)
//     4. Plunge Z back to deep    (return to the deeper position)
//   Ending condition: nozzle is DOWN in pocket (at original + 100 deeper).
//   Caller should lift to travel Z afterward.
// Example: ADVANCE Y430 Z5000
void handleAdvance(String cmd) {
  long pitch = 0;
  long travelZ = 0;
  bool hasY = false, hasZ = false;

  int idx;
  if ((idx = cmd.indexOf('Y')) >= 0) { pitch = cmd.substring(idx+1).toInt(); hasY = true; }
  if ((idx = cmd.indexOf('Z')) >= 0) { travelZ = cmd.substring(idx+1).toInt(); hasZ = true; }

  if (!hasY || pitch == 0) {
    Serial.println("ERR: ADVANCE requires Y<pitch>");
    return;
  }
  if (!hasZ) {
    Serial.println("ERR: ADVANCE requires Z<travelZ>");
    return;
  }

  // Remember where we started (nozzle is currently in the pocket at pickup Z)
  long startZ = motorZ.currentPosition();

  // Step 0: plunge 100 deeper to grip the tape hole
  // Z+ is DOWN on this machine
  long deepZ = startZ + 100;
  motorZ.moveTo(deepZ);
  while (motorZ.distanceToGo() != 0) {
    runMotorWithLimit(motorZ, Z_LIMIT_PIN, Z_LIMIT_IS_POSITIVE, "Z", zLimitCounter);
  }

  // Step 1: drag Y by -pitch (scroll tape backward, nozzle gripping hole)
  motorY.move(-pitch);
  while (motorY.distanceToGo() != 0) {
    runMotorWithLimit(motorY, Y_LIMIT_PIN, Y_LIMIT_IS_POSITIVE, "Y", yLimitCounter);
  }

  // Step 2: lift Z to travel height (absolute)
  motorZ.moveTo(travelZ);
  while (motorZ.distanceToGo() != 0) {
    runMotorWithLimit(motorZ, Z_LIMIT_PIN, Z_LIMIT_IS_POSITIVE, "Z", zLimitCounter);
  }

  // Step 3: return Y by +pitch (head back over original pocket)
  motorY.move(pitch);
  while (motorY.distanceToGo() != 0) {
    runMotorWithLimit(motorY, Y_LIMIT_PIN, Y_LIMIT_IS_POSITIVE, "Y", yLimitCounter);
  }

  // Step 4: plunge back to deep position (startZ + 100)
  motorZ.moveTo(deepZ);
  while (motorZ.distanceToGo() != 0) {
    runMotorWithLimit(motorZ, Z_LIMIT_PIN, Z_LIMIT_IS_POSITIVE, "Z", zLimitCounter);
  }

  Serial.println("OK");
}
void doPick() {
  // Drop Z, vacuum ON, raise Z
  motorZ.move(Z_DROP_STEPS);
  while (motorZ.distanceToGo() != 0) {
    runMotorWithLimit(motorZ, Z_LIMIT_PIN, Z_LIMIT_IS_POSITIVE, "Z", zLimitCounter);
  }
  digitalWrite(PUMP_PIN, HIGH);
  delay(200);
  motorZ.move(Z_LIFT_STEPS);
  while (motorZ.distanceToGo() != 0) {
    runMotorWithLimit(motorZ, Z_LIMIT_PIN, Z_LIMIT_IS_POSITIVE, "Z", zLimitCounter);
  }
}

void doPlace() {
  motorZ.move(Z_DROP_STEPS);
  while (motorZ.distanceToGo() != 0) {
    runMotorWithLimit(motorZ, Z_LIMIT_PIN, Z_LIMIT_IS_POSITIVE, "Z", zLimitCounter);
  }
  digitalWrite(PUMP_PIN, LOW);
  delay(200);
  motorZ.move(Z_LIFT_STEPS);
  while (motorZ.distanceToGo() != 0) {
    runMotorWithLimit(motorZ, Z_LIMIT_PIN, Z_LIMIT_IS_POSITIVE, "Z", zLimitCounter);
  }
}

// ─── HOMING (identical to reference sketch) ──────────────────────────────
void doHoming() {
  homeAxis(motorX, X_LIMIT_PIN, X_HOMING_SPEED, "X");
  delay(500);
  homeAxis(motorY, Y_LIMIT_PIN, Y_HOMING_SPEED, "Y");
  delay(500);
  homeAxis(motorZ, Z_LIMIT_PIN, Z_HOMING_SPEED, "Z");
  delay(500);
  motorR.setCurrentPosition(0);
}

void homeAxis(AccelStepper &motor, int limitPin, float speed, const char* axisName) {
  Serial.print("Homing ");
  Serial.print(axisName);
  Serial.println(" axis...");

  motor.setSpeed(speed);

  // NC + INPUT_PULLUP: not pressed = LOW, pressed = HIGH
  while (digitalRead(limitPin) == LOW) {
    motor.runSpeed();
  }

  motor.setSpeed(0);
  motor.setCurrentPosition(0);

  Serial.print(axisName);
  Serial.println(" axis homed.");
}

// ─── LIMIT-PROTECTED RUN (identical to reference sketch) ─────────────────
void runMotorWithLimit(
  AccelStepper &motor, int limitPin, bool limitIsPositive,
  const char* axisName, byte &limitCounter
) {
  long distance = motor.distanceToGo();
  bool movingPositive = distance > 0;
  bool movingNegative = distance < 0;

  bool movingTowardLimit =
    (limitIsPositive && movingPositive) ||
    (!limitIsPositive && movingNegative);

  if (movingTowardLimit) {
    bool switchPressed = digitalRead(limitPin) == HIGH;
    if (switchPressed) {
      if (limitCounter < LIMIT_DEBOUNCE_COUNT) limitCounter++;
    } else {
      limitCounter = 0;
    }
    if (limitCounter >= LIMIT_DEBOUNCE_COUNT) {
      long current = motor.currentPosition();
      motor.moveTo(current);
      motor.setSpeed(0);
      Serial.print("LIMIT HIT on ");
      Serial.print(axisName);
      Serial.println(" axis. Motor stopped.");
      limitCounter = 0;
      return;
    }
  } else {
    limitCounter = 0;
  }

  motor.run();
}

// ─── REPORTING ───────────────────────────────────────────────────────────
void reportPosition() {
  Serial.print("X:");  Serial.print(motorX.currentPosition());
  Serial.print(" Y:"); Serial.print(motorY.currentPosition());
  Serial.print(" Z:"); Serial.print(motorZ.currentPosition());
  Serial.print(" R:"); Serial.println(motorR.currentPosition());
}

void printSwitches() {
  Serial.print("X limit: "); Serial.print(digitalRead(X_LIMIT_PIN));
  Serial.print(" | Y limit: "); Serial.print(digitalRead(Y_LIMIT_PIN));
  Serial.print(" | Z limit: "); Serial.println(digitalRead(Z_LIMIT_PIN));
  Serial.println("With NC + INPUT_PULLUP: 0 = not pressed, 1 = pressed/open");
}

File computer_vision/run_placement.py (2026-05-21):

"""
run_placement.py
================
Automated placement CLI — runs the full vision-check sequence end-to-end.

This replaces the manual n/+/- navigation in pnp_bottom_vision.py for production
runs.  pnp_bottom_vision.py stays in place as the manual debug/tuning tool.

Usage:
    python run_placement.py

Keyboard shortcuts:
    SPACE  — process the current expected designator (capture → detect → send → ACK)
    s      — skip current component (operator override after a WRONG_PART halt)
    r      — reset to start of queue
    q      — quit

Configuration:
    Edit the constants below (CAMERA_INDEX, SERIAL_PORT, PCB_FILE).
"""

import cv2
import numpy as np
import time
from typing import Optional

from orientation_engine import (
    OrientationResult,
    FRAME_WIDTH, FRAME_HEIGHT, CENTER_RADIUS,
)
from placement_sequencer import PlacementSequencer, SequencerStatus, SequencerResult

# ── Configuration ─────────────────────────────────────────────────────────────
CAMERA_INDEX = 1
SERIAL_PORT  = "COM3"
BAUD_RATE    = 115200
PCB_FILE     = r"C:\Users\Admin\Downloads\flashing-led-all.pos"
VERBOSE      = True


# ── Colours ───────────────────────────────────────────────────────────────────
_COLORS = {
    "RESISTANCE":   ( 50, 255, 100),
    "CONDENSATEUR": (  0, 160, 255),
    "LED":          (  0,  80, 255),
    "SMD_PASSIVE":  (255,   0, 200),
    "IC":           (  0, 220, 220),
    "ELCAP":        (  0, 200, 255),
    "CONNECTOR":    (255, 140,   0),
    "INCONNU":      (130, 130, 130),
}

_STATUS_COLORS = {
    SequencerStatus.OK_PLACED:      (0, 230,   0),
    SequencerStatus.NEEDS_ROTATION: (0, 160, 255),
    SequencerStatus.WRONG_PART:     (0,   0, 255),
    SequencerStatus.NO_DETECTION:   (0, 100, 255),
    SequencerStatus.RETRY:          (0, 200, 200),
}


# ── Drawing helpers ───────────────────────────────────────────────────────────

def draw_result(frame: np.ndarray,
                seq_result: Optional[SequencerResult],
                designator: str) -> np.ndarray:
    out = frame.copy()
    H, W = out.shape[:2]
    cx0, cy0 = W // 2, H // 2

    cv2.line(out,   (cx0 - 50, cy0), (cx0 + 50, cy0), (60, 60, 60), 1)
    cv2.line(out,   (cx0, cy0 - 50), (cx0, cy0 + 50), (60, 60, 60), 1)
    cv2.circle(out, (cx0, cy0), CENTER_RADIUS, (40, 40, 40), 1)
    cv2.putText(out, f"Target: {designator}", (W - 270, 35),
                cv2.FONT_HERSHEY_SIMPLEX, 0.9, (220, 220, 220), 2)

    if seq_result is None or seq_result.orientation is None:
        msg = "Hold component under camera, then press SPACE"
        if seq_result and seq_result.status == SequencerStatus.NO_DETECTION:
            msg = f"No detection — {seq_result.message}"
        elif seq_result and seq_result.status == SequencerStatus.WRONG_PART:
            msg = f"WRONG PART — {seq_result.message}  (s=skip)"
        cv2.putText(out, msg, (20, 50),
                    cv2.FONT_HERSHEY_SIMPLEX, 0.65, (0, 100, 255), 2)
        return out

    result = seq_result.orientation
    comp   = result.component
    color  = _COLORS.get(comp.comp_type, (255, 255, 255))
    s_color = _STATUS_COLORS.get(seq_result.status, (200, 200, 200))

    bx = comp.cx - comp.width  // 2
    by = comp.cy - comp.height // 2
    cv2.rectangle(out, (bx, by), (bx + comp.width, by + comp.height), color, 2)
    cv2.circle(out, (comp.cx, comp.cy), 5, color, -1)

    ang = np.radians(comp.angle)
    cv2.arrowedLine(out, (comp.cx, comp.cy),
                    (int(comp.cx + 70 * np.cos(ang)),
                     int(comp.cy + 70 * np.sin(ang))),
                    color, 2, tipLength=0.3)

    if result.pcb_comp:
        req = np.radians(result.required_angle)
        cv2.arrowedLine(out, (comp.cx, comp.cy),
                        (int(comp.cx + 70 * np.cos(req)),
                         int(comp.cy + 70 * np.sin(req))),
                        (0, 230, 230), 2, tipLength=0.3)

    for px, py in comp.pad_positions:
        cv2.circle(out, (px, py), 7, (0, 255, 255), 2)

    pin1_txt = f"  pin1={comp.pin1_side}" if comp.pad_count >= 6 else ""
    lines = [
        f"Type    : {comp.comp_type}",
        f"Conf    : {comp.confidence * 100:.0f}%",
        f"Pads    : {comp.pad_count}{pin1_txt}",
        f"Method  : {comp.angle_method}",
        f"Current : {comp.angle:.1f} deg",
        f"Required: {result.required_angle:.1f} deg",
        f"Delta   : {result.delta_angle:+.1f} deg",
        f"Status  : {seq_result.status.name}",
    ]
    panel_h = len(lines) * 28 + 20
    cv2.rectangle(out, (8, 8), (420, 8 + panel_h), (0, 0, 0), -1)
    cv2.rectangle(out, (8, 8), (420, 8 + panel_h), s_color, 2)
    for i, ln in enumerate(lines):
        cv2.putText(out, ln, (18, 36 + i * 28),
                    cv2.FONT_HERSHEY_SIMPLEX, 0.6,
                    s_color if i == 7 else (240, 240, 240), 1)

    if seq_result.status == SequencerStatus.OK_PLACED:
        banner = f"  PLACED {designator}  "
    elif seq_result.status == SequencerStatus.WRONG_PART:
        banner = f"  WRONG PART / REJECT  (s=skip)  "
    elif seq_result.status in (SequencerStatus.NEEDS_ROTATION,
                                SequencerStatus.RETRY):
        banner = f"  {result.action}  {abs(result.delta_angle):.1f}°  — re-press SPACE  "
    else:
        banner = f"  {seq_result.message}  "

    cv2.rectangle(out, (0, H - 55), (W, H), s_color, -1)
    cv2.putText(out, banner, (20, H - 16),
                cv2.FONT_HERSHEY_SIMPLEX, 0.9, (0, 0, 0), 2)

    return out


# ── Combined debug view ───────────────────────────────────────────────────────
#
# Single 1280×720 canvas layout:
#
#  ┌─────────────────────┬────────────────┬────────────────┐  ← row 0, h=410
#  │  Camera + result    │   Pad zoom     │   Body mask    │
#  │  (640×410)          │   (320×410)    │   (320×410)    │
#  ├──────────┬──────────┼──────────┬─────┴────────────────┤  ← row 1, h=310
#  │  Color   │  Shape   │ Thresh.  │  Decision tree       │
#  │  (320×310)│(320×310)│  (320×310)│  (320×310)          │
#  └──────────┴──────────┴──────────┴─────────────────────-┘
#
# Press 'd' to toggle bottom debug row on/off.

_FONT  = cv2.FONT_HERSHEY_SIMPLEX
_SMALL = 0.40
_MED   = 0.50
_DIVIDER_COLOR = (45, 45, 45)


def _panel(h: int, w: int, title: str, title_color=(180, 180, 180)) -> np.ndarray:
    p = np.full((h, w, 3), 22, dtype=np.uint8)
    cv2.rectangle(p, (0, 0), (w - 1, h - 1), (55, 55, 55), 1)
    cv2.putText(p, title, (6, 16), _FONT, _SMALL, title_color, 1)
    cv2.line(p, (0, 20), (w, 20), (55, 55, 55), 1)
    return p
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

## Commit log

2026-04-30 added the files related to the demo circuits
2026-05-12 first version of computer vision
    [pcb_centroid.csv]
2026-05-13 Add files via upload
    with the help of @yahya we managed to capture all the plate component coordinates.
    This excel holds the data.
    now knowing the coordinates we can have a full functional pipeline
    [3D PLACER COORDINATES.xlsx]
2026-05-14 added the ui of the webapp and the logic of going from the pos file to arduino commands
2026-05-14 updated computer vision, pos file detection integrated
    [flashing-led.csv, pcb_centroid.csv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]
2026-05-16 a working version that detctets 2/4 components correctly
    [orientation_engine.py]
2026-05-17 added the 3D designs I made so far for the project
    [BottomLightHolder.stl, BottomSprocket.stl, FeederBody.step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]
2026-05-18 added the designs for the nozzle tips
    [TipBig.stl, TipSmall.stl]
2026-05-21 A very good version of the computer vision: with a green background and a stable surface that holdes the pieces, it detects and differentiate between a LED, a capacitor, a resistor and a timer
    [flashing-led-all.csv, flashing-led.csv, pcb_centroid.csv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]
2026-05-21 Update README with electronics assembly details
    Added details about the electronics assembly of the project, including components and their functions.
2026-05-21 added more 3D designs: plate, spacers and PCB holder
    [PCBHolder.3mf, Plate.dxf, PlateSpacer.stl]
2026-05-21 added pictures of the circuit
2026-05-21 added the electronic circuit
2026-05-25 Enhance README with CV module electronics details
    Added detailed electronics assembly instructions for the CV module, including hardware components, wiring diagram, and visual setup.
2026-05-26 Add BUCK Converter information to README
2026-05-28 added the 3D design of the nozzle gear
    [NozzleGear.step]
